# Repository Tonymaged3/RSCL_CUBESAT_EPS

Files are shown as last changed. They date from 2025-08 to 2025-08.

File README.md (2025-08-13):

# RSCL_CUBESAT_EPS
# CubeSat Electric Power System (EPS) – Senior Design Project

**Author:** Antonuos Kerollos  

## Overview
This repository contains the design files for a high-efficiency Electric Power System (EPS) intended for CubeSat missions.  
The EPS is engineered to:
- Harvest solar energy efficiently.
- Manage and protect power distribution.
- Extend battery life through intelligent switching.
- Operate reliably under harsh thermal and radiation conditions in space.

The project implements:
- Maximum Power Point Tracking (MPPT) charging.
- Custom analog automatic battery switching.
- Regulated power outputs for satellite subsystems.
- Real-time monitoring of voltage, current, and power.
- Radiation-tolerant, microcontroller-minimized control.

---

## System Architecture

**Key Subsystems:**
1. **Solar Energy Harvesting:**  
   - Monocrystalline solar panels arranged in deployable arrays for up to **5.5 W** generation under full sunlight.
   - Series pairs configuration for optimal efficiency.

2. **Battery Management:**  
   - Two battery banks (20 Ah total) with alternating charge/discharge cycles to avoid overcharging and extend lifespan.
   - Custom switching circuit using ideal diodes and comparators.

3. **Power Regulation & Distribution:**  
   - 3.3 V and 5 V regulated rails for different CubeSat loads.
   - High-side power switch for load control and protection.

4. **Monitoring & Fault Protection:**  
   - INA219 sensors for voltage, current, and power telemetry.
   - Temperature sensors for solar charger compensation.
   - Reverse current protection from solar panel transients.

5. **Deployment & Thermal Management:**  
   - Burn wire deployment for antennas and solar panels.
   - Battery heater circuit to maintain optimal operating temperature.

---
eps_block_diagram

## Component List & Circuit Roles

| Component | Type | Purpose in EPS |
|---|---|---|
| **SM401K08L** | Monocrystalline Solar Cell | High-efficiency power generation (702 mW @ 5.53 V each). |
| **LT3652** | MPPT Charger IC | Tracks solar panel maximum power point and charges battery efficiently. |
| **LTC4415** | Ideal Diode Power Path Controller | Switches between battery banks with minimal loss. |
| **TLV3012B** | Comparator | Monitors solar panel voltage to control battery switching logic. |
| **LTC3113** | DC-DC Converter | Regulates output to stable 3.3 V for CubeSat electronics. |
| **TPS61023** | Boost Converter | Regulates output to 5 V for specific subsystems. |
| **TPS1HC30** | High-Side Power Switch | Controls and protects loads from overcurrent events. |
| **INA219** | Power Monitor | Measures voltage, current, and power for real-time telemetry. |
| **TCAL9539** | I²C Expander | Extends microcontroller I/O for deployment and thermal systems. |
| **LM74610** | Ideal Diode | Prevents reverse current from solar panels. |
| **Battery Heater Circuit** | Custom | Maintains battery temperature in optimal range. |
| **Burn Wire Deployment Circuit** | Custom | Releases antennas and solar panels on command. |

---

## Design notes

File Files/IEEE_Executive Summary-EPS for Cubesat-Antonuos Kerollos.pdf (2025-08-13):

# Electric Power System Design for Reconfigurable CubeSat Clusters

Antonuos Kerollos
Department of Electrical and Computer Engineering, College of Engineering California State Polytechnic University, Pomona Pomona, CA, USA
amkerollos@cpp.edu
Faculty Advisor: Dr. Mohamed El Hadedy Aly

Abstract—This project presents the design and implementation of a high-efficiency Electric Power System (EPS) for CubeSat missions. The system addresses key challenges in space-based power management such as limited surface area for solar collection, battery longevity, space constraints, and radiation-induced failures. A custom analog-based switching topology and MPPT solar charging circuit are used to maximize power efficiency, safety, and mission reliability. Simulation and testing validate the effectiveness of the approach. A 4-layer PCB layout integrates all components for flight readiness.
Index Terms—CubeSat, Electric Power System, MPPT, LTC3652, LTC4415, Single-Event Upset, SEU, Analog Switching, PCB Design
I. INTRODUCTION

The purpose of this project is to design and implement a high-efficiency Electric Power System (EPS) that can reliably support the operation of a CubeSat throughout the duration of its mission. The EPS is the core system responsible for powering all onboard subsystems, and its performance directly impacts the mission’s success and longevity. The main objective is to deliver a compact, efficient, and reliable EPS capable of harvesting solar energy, managing power distribution, and safely storing energy in onboard batteries. The system must maintain stable voltage levels, protect components from electrical faults or any single-event upset, and provide real-time power monitoring while operating under space and weight constraints inherent to CubeSat platforms. The EPS must also prioritize energy efficiency to maximize battery life and extend the mission’s operational time.
This project addresses several key challenges:
- Maximizing energy conversion efficiency from limited solar panel surface area.
- Managing power storage and distribution for variable subsystem loads.
- Mitigating Single-Event Upsets (SEUs) caused by space radiation.
- Operating within strict space and mass constraints.
- Ensuring system stability and safety in high-temperature environments.
- Providing real-time monitoring and control to adapt to orbital power conditions.

II. LITERATURE REVIEW

The first and most critical problem addressed in our design is the efficiency gap between the amount of solar energy that can be harvested and how much of that energy can be effectively stored in the batteries. To address this, we selected the SM401K08L monocrystalline solar cell, rated at 702 mW and 5.53 V, with physical dimensions of 90 mm × 40 mm. Two cells are connected in series to produce up to 1.4 W per pair. This configuration is significantly more space-efficient than other CubeSat approaches that rely on either a single large panel or many smaller panels, which often suffer from power losses due to wiring resistance and interconnect complexity. By integrating five series-connected pairs—mounted on the top and four sides of the CubeSat—and deploying them using a mechanism similar to antenna deployment systems, we can generate up to 5.5 W under full sun exposure.
To convert and store the harvested energy, we employed the LT3652 Maximum Power Point Tracking (MPPT) charger. This IC dynamically adjusts its input to extract the maximum available power from the solar panels. Unlike traditional EPS designs that connect the charger output in parallel with both the load and the batteries, our design isolates these paths to avoid overcharging risks. In parallel configurations, the battery may continue charging unnecessarily when the load is drawing current, even after the battery is full. Additionally, this setup causes the battery to operate in a narrow voltage range and frequently alternate between charging and discharging states, which accelerates degradation.
To overcome these issues, we designed a custom analog automatic power switch circuit. This circuit separates the energy storage into two independent battery units. One unit is isolated for charging, while the other supplies power to the load. The LT3652 is connected in series with the charging battery, allowing it to monitor charge conditions accurately. The switching mechanism uses an LTC4415 ideal diode and is controlled by a TLV3012B comparator, which senses solar panel voltage. When sunlight is available, the comparator toggles the switch to isolate the charging battery and route the load to the other unit. Once solar input is lost, the switch reverts, making the charged battery available to the system and isolating the other for recharging in the next cycle.

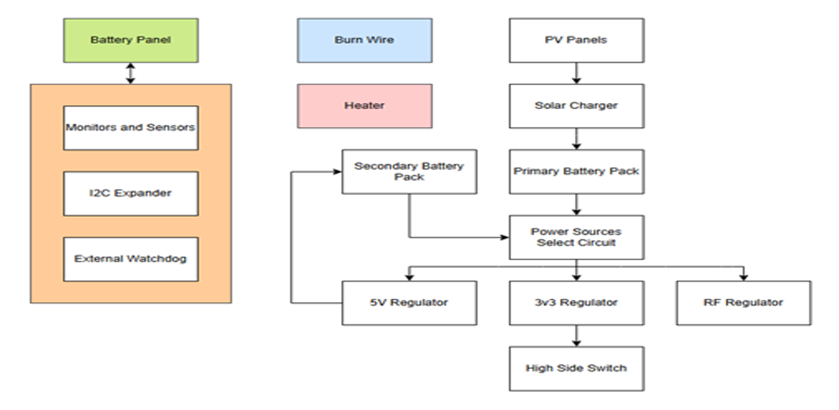
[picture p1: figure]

Fig. 1: Electrical Power System Block Diagram showing solar input, switching logic, MPPT charging, regulation, and battery units.

For efficient energy distribution, we used low-power regulators: the LTC3113 for 3.3V and the TPS61023 for 5V output. These deliver stable voltage rails for the CubeSat subsystems. A TPS1HC30 high-side switch protects the power path, and INA219 sensors are integrated to monitor current, voltage, and power in real time, providing telemetry to the main microcontroller.
To increase radiation resilience, the EPS logic minimizes reliance on digital microcontrollers and register-based logic. Instead, analog circuitry is used for core operations, significantly reducing susceptibility to Single-Event Upsets (SEUs)—bitflipping events caused by high-energy particles in space. This analog-dominant architecture avoids runtime-dependent firmware and volatile memory, enhancing system robustness in radiation-prone orbits.
All components are selected to operate reliably up to 125°C, ensuring thermal resilience in lunar orbit conditions. Three temperature sensors are also added to the solar charger to compensate for panel voltage shifts due to thermal variations. The open-circuit voltage temperature coefficient of –13.92 mV/K is dynamically corrected, improving energy capture under fluctuating conditions—a feature rarely seen in comparable CubeSat systems.
For expanded control, we integrated a TCAL9539 I²C expander, allowing the MCU to programmatically pull pins high or low. This enables manual overrides and control of subsystems, such as the thermal and deployment circuits. Additionally, LM74610 ideal diodes were added to prevent reverse current flow from the solar panels into the charging path.
Finally, the EPS board includes a burn-wire circuit for both antenna and solar panel deployment, as well as a battery heater circuit to maintain the batteries within optimal operating temperatures. Both circuits are controlled by the MCU through the I²C expander, ensuring reliable execution of missioncritical functions across varying orbital environments.

III. RESULTS AND DISCUSSION

To validate the performance and reliability of the power management system, we conducted multiple simulations and hardware tests focusing on the automatic switching topology, solar energy harvesting, battery behavior, and charging efficiency.
Using LTspice, I simulated the auto-switching power management circuitry. This design uses a TLV3012B comparator to control the enable pin of the LTC4415 power path controller, toggling between two battery units based on solar panel voltage levels. In the simulation, a pulse generator was used to mimic the behavior of the comparator, switching the control logic depending on light availability.

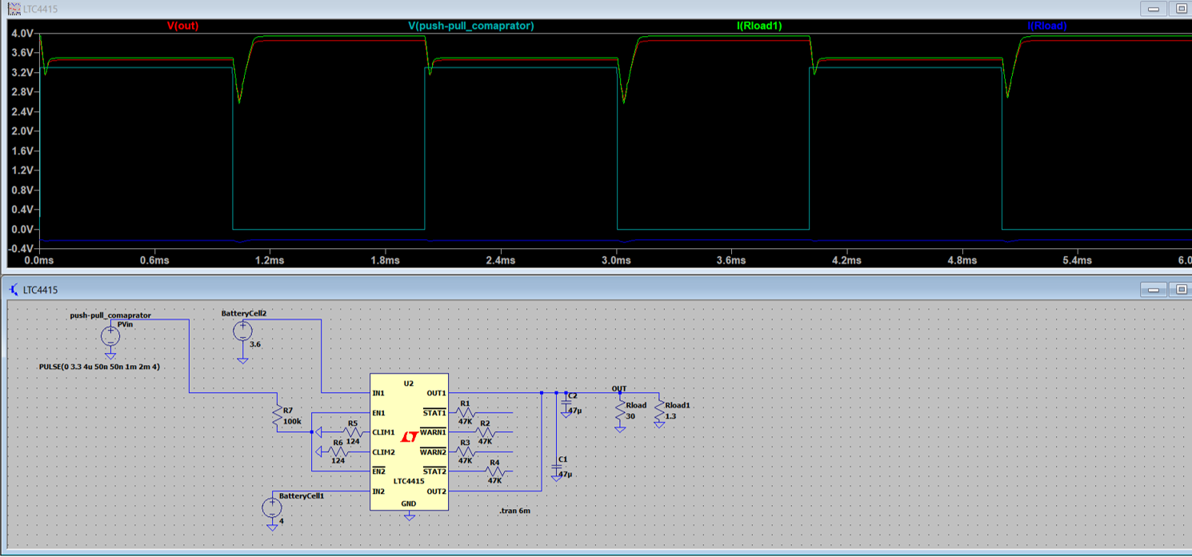
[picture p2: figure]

Fig. 2: LTSpice Simulation for the Auto-Switching Circuit

We tested different output capacitances to evaluate the voltage and current drop during switching events. When using an 80 µF capacitor at the output of the LTC4415, the simulation showed a 360 mV (11%) voltage drop and a 100 mA (10%) current drop. These transient variations are within acceptable limits and do not adversely affect the load. Further optimization using two 47 µF capacitors reduced these drops to 7%, confirming that the switching topology operates efficiently and can handle transitions without significantly impacting system stability.
In addition to simulations, real hardware components were evaluated. The solar panels were tested under standard illumination, and their current and voltage outputs matched rated specifications, validating our theoretical calculations. Similarly, the Li-ion batteries were tested to ensure their voltage, capacity, and charging behavior were within expected tolerances.
We also tested the LT3652 MPPT charger, which successfully activated its fault detection outputs. However, it failed to begin charging during early tests due to the exposed thermal pad not being properly connected to ground, a known requirement per the datasheet. Once addressed in the PCB layout, proper charging behavior is expected.
The use of flight-proven components throughout the EPS design, including the LTC4415, LT3652, TPS61023, and INA219, provided additional confidence in system reliability. Many of these ICs have heritage in previous CubeSat missions, further reinforcing their suitability for space applications.
We also conducted a power rating and efficacy study for our EPS. The energy conversion efficacy due to typical losses (resistance, wiring, and hardware) was estimated between 70% and 90%. Using this factor:
- A pair of panels in series: 1404 mW × 0.8 = 1.1 W

- Three series pairs: 3 × 1.1 W = 3.3 W
- Four series pairs: 4 × 1.1 W = 4.4 W
With five pairs of solar panels, the estimated total power generated is approximately 5.5 W under full sun exposure. For storage, the system uses four 5000 mAh batteries, totaling 20 Ah. Based on a conservative energy availability estimate in Low Lunar Orbit (LLO)—where sunlight is guaranteed for at least 30 minutes per 2-hour orbital period—we expect to generate a minimum of 2 W per cycle. Assuming the load requires 1 W per hour, the power budget is sufficient to support basic CubeSat operations with redundancy, while also compensating for periods of eclipse or reduced solar exposure. These results confirm that the EPS topology functions as intended, with reliable energy harvesting, intelligent switching, and regulated power delivery, while maintaining operational safety and extending battery and mission life.
In addition to simulation and component-level testing, a complete schematic of the entire Electric Power System was implemented, followed by full 4-layer PCB layout and routing. The board was designed to integrate all power generation, regulation, switching, and monitoring components into a compact, reliable form factor suitable for CubeSat deployment. Signal, ground, and power planes were carefully distributed across the four layers to optimize thermal performance, reduce EMI, and ensure power integrity. Input/output pins and onboard connectors were also included to support integration with the satellite’s batteries, solar panels, and other subsystems. The layout emphasizes low-resistance paths for high-current traces, controlled impedance for signal lines, and overall electrical and thermal robustness. While the design is ready for fabrication and testing, a final round of routing refinement and design rule verification is required to ensure compliance with fabrication constraints and improve long-term reliability.

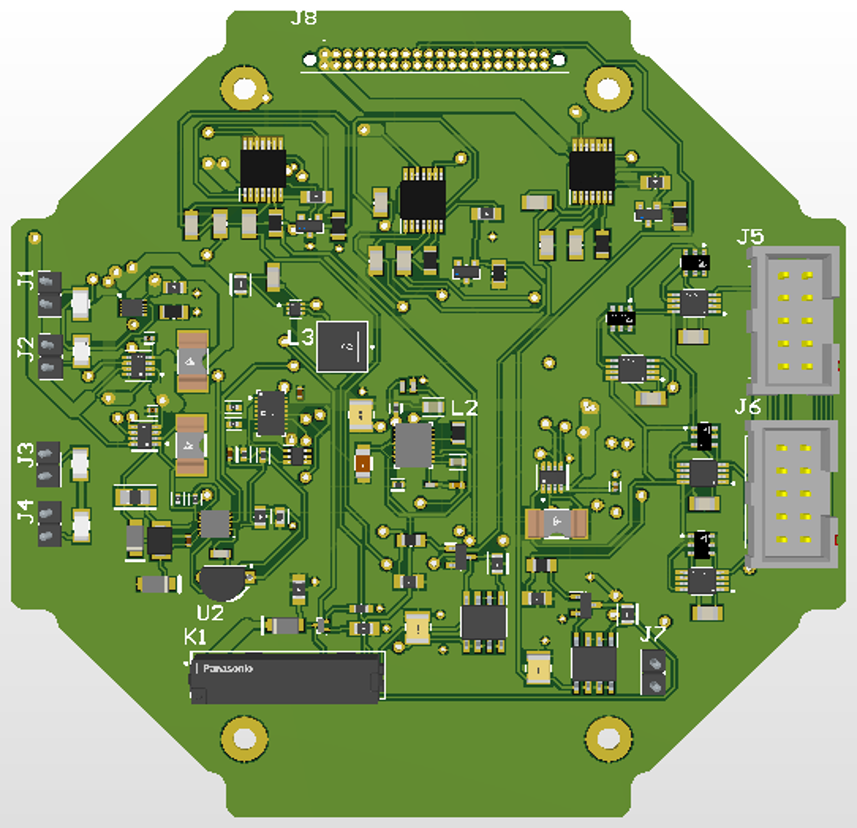
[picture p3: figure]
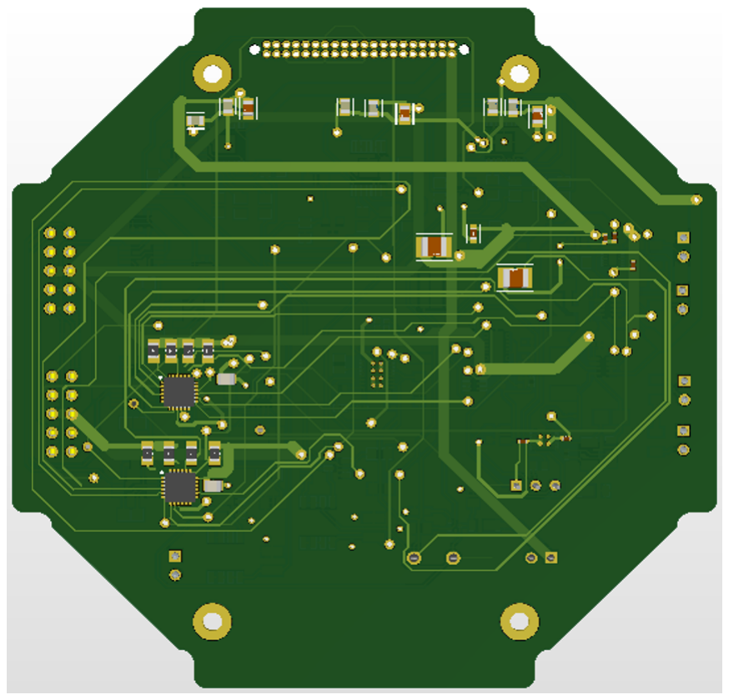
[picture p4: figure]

(a) Top layer view | (b) Bottom layer view

Fig. 3: CubeSat EPS PCB Design showing both top and bottom layout layers.

IV. CONCLUSION
This project successfully delivers a comprehensive and efficient Electric Power System (EPS) tailored to the constraints and requirements of CubeSat missions. By systematically addressing the core challenges in space-based power design, the final implementation demonstrates both innovation and reliability. The use of high-efficiency monocrystalline solar panels, coupled with an advanced MPPT charging system, ensures maximum energy extraction from the limited available surface area. The custom analog-based power switching topology enables intelligent battery management, avoiding harmful charge-discharge cycles and significantly extending battery life.
Space and mass constraints were overcome through a compact 4-layer PCB layout that integrates all subsystems including regulation, monitoring, fault protection, and thermal management into a single board. The design supports stable operation in extreme temperature environments, with all components rated up to 125°C and thermal feedback mechanisms included for improved energy conversion under changing conditions. Real-time power monitoring is enabled via lowoverhead digital sensors and an I²C expander, while critical safety functions like deployment and heating are directly controlled through onboard logic.
Importantly, the system minimizes dependence on microcontrollers and register-based digital logic, reducing vulnerability to radiation-induced Single-Event Upsets (SEUs) and enhancing overall mission resilience. With the full schematic implemented and a 4-layer PCB routed and ready for fabrication, the EPS is positioned as a robust, flight-ready solution. Once final routing refinements are completed, the board will be ready for manufacturing and integration. The design not only meets mission objectives for reliability and efficiency but also offers modular and scalable power architecture applicable to future CubeSat and small satellite platforms.

ACKNOWLEDGMENT
The author would like to sincerely thank Dr. Mohamed El Hadedy Aly for his continued guidance and support as the faculty advisor for this project. His expertise and feedback were instrumental throughout the design and development of the CubeSat Electric Power System. For correspondence, he may be reached at mealy@cpp.edu.

REFERENCES

[1] PyCubed, PyCubed Hardware GitHub Repository. [Online]. Available: https://github.com/pycubed/hardware/tree/master
[2] NASA, CubeSat 101: Basic Concepts and Processes for First-Time CubeSat Developers. NASA, Mar. 2017. [Online]. Available: https://www.nasa.gov/wp-content/uploads/2017/03/nasa csli cubesat 101 508.pdf
[3] United Nations Office for Outer Space Affairs (UNOOSA), KiboCUBE Academy 2021 – On-demand Pre-recorded Lecture: EPS Design Considerations. [Online]. Available: https://www.unoosa.org/documents/pdf/psa/access2space4all/KiboCUBE/AcademySeason2/On-demand Pre-recorded Lectures/KiboCUBE Academy 2021 OPL08.pdf
[4] M. Holliday, K. Tracy, Z. Manchester, and A. Nguyen, “The V-R3x Mission: Towards Autonomous Networking and Navigation for CubeSat Swarms,” 4S Symposium, 2022. [Online]. Available: https://rexlab.ri.cmu.edu/papers/vr3x.pdf

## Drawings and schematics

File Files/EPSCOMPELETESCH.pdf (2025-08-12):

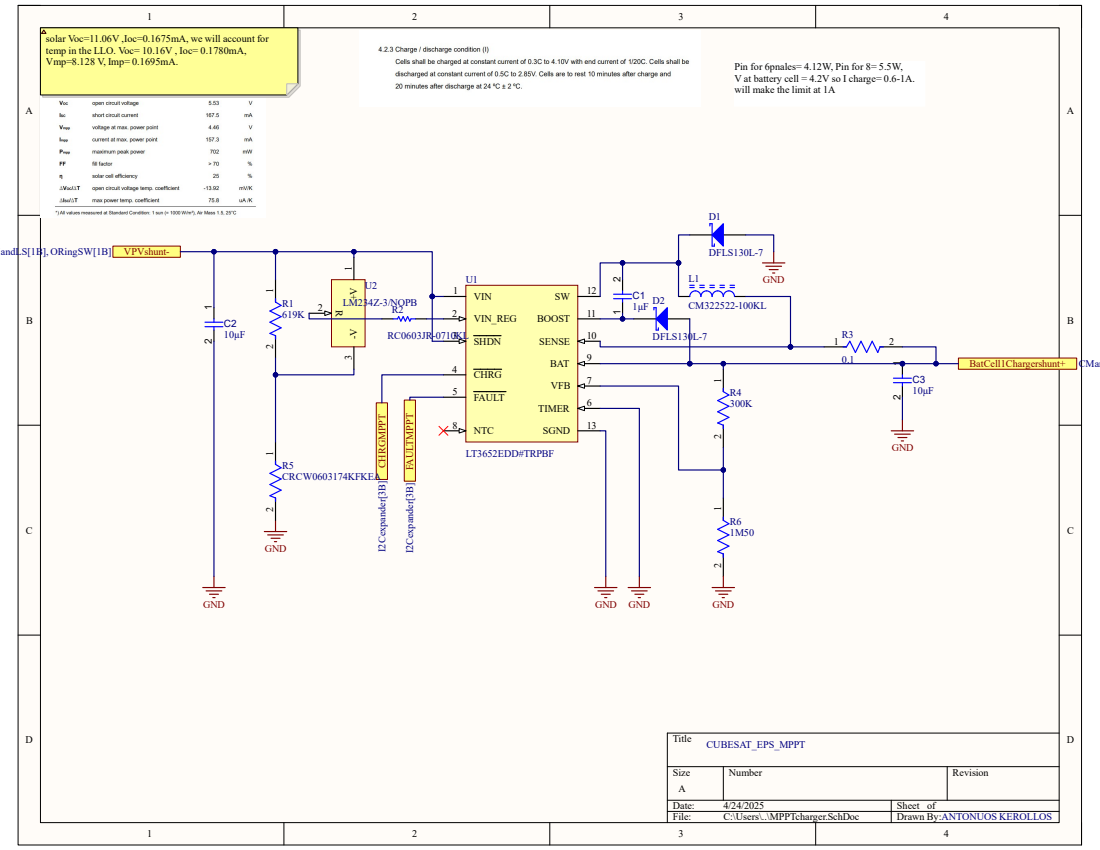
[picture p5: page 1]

solar Voc=11.06V ,Ioc=0.1675mA, we will account for
temp in the LLO. Voc= 10.16V , Ioc= 0.1780mA,
Vmp=8.128 V, Imp= 0.1695mA.

Pin for 6pnales= 4.12W, Pin for 8= 5.5W,
V at battery cell = 4.2V so I charge= 0.6-1A.
will make the limit at 1A

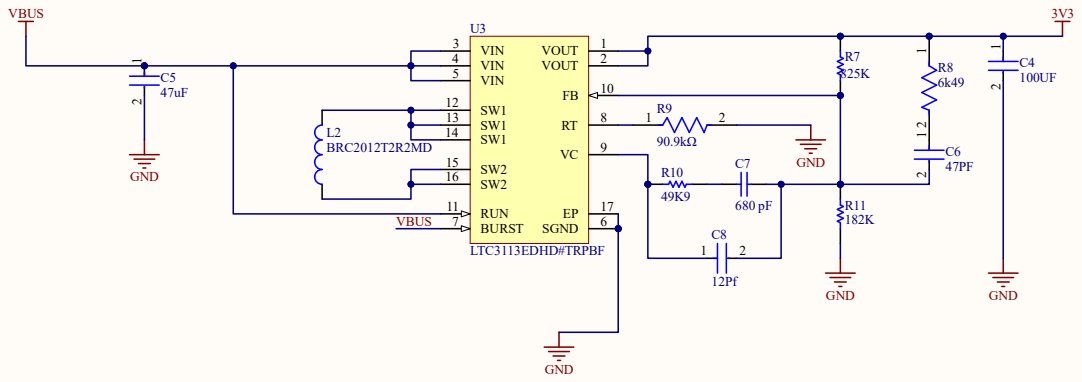
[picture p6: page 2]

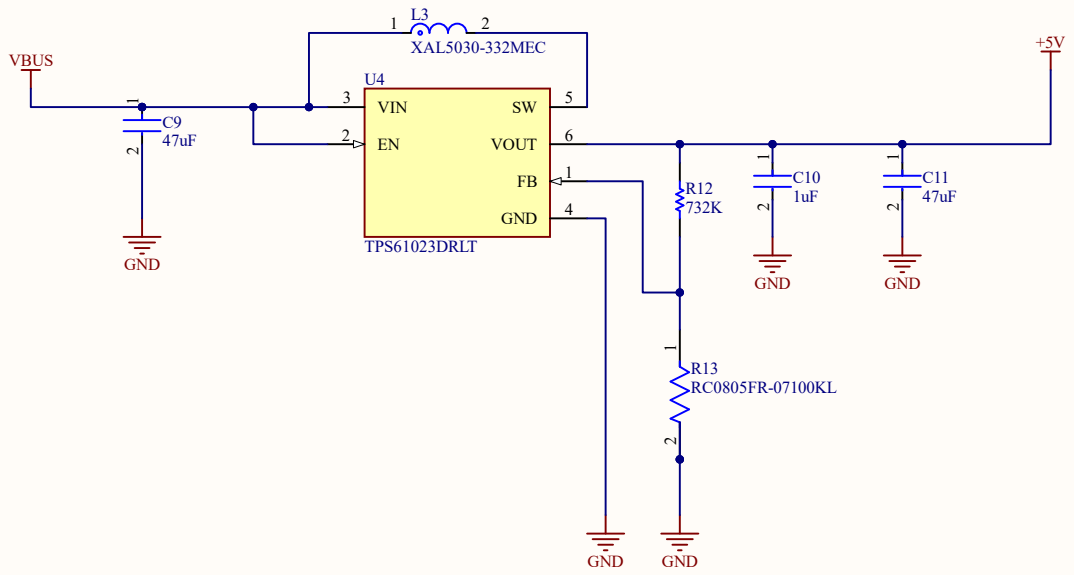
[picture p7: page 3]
Title; Size; Number; Revision; File:; C:\Users\..\REG5V.SchDoc; Drawn By:; VIN 3; VOUT; GND; TPS61023DRLT; VBUS; XAL5030-332MEC; CUBESAT_EPS_REG5V

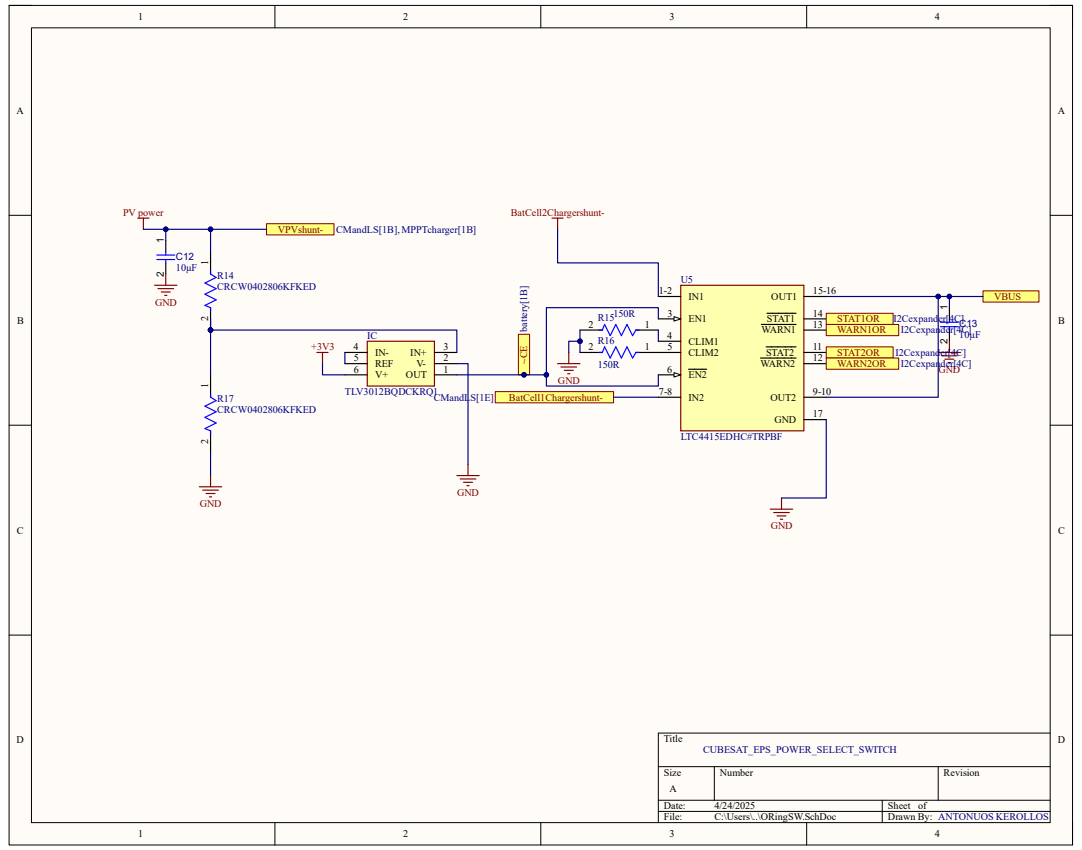
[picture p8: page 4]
Title; Size; Number; Revision; File:; C:\Users\..\ORingSW.SchDoc; Drawn By:; CLIM1 4 CLIM2 5; OUT1; OUT2; STAT1; STAT2; WARN1; WARN2; GND; LTC4415EDHC#TRPBF; PV power; VBUS; GND ~CE battery[1B]; STAT1OR I2Cexpander[4C]; WARN1OR; I2Cexpander[4C]; STAT2OR; WARN2OR; BatCell2Chargershunt-; CMandLS[1E]; BatCell1Chargershunt-; OUT; REF 5; TLV3012BQDCKRQ1; R14 CRCW0402806KFKED 1 2; R17 CRCW0402806KFKED; CUBESAT_EPS_POWER_SELECT_SWITCH

VPVshunt- CMandLS[1B], MPPTcharger[1B]

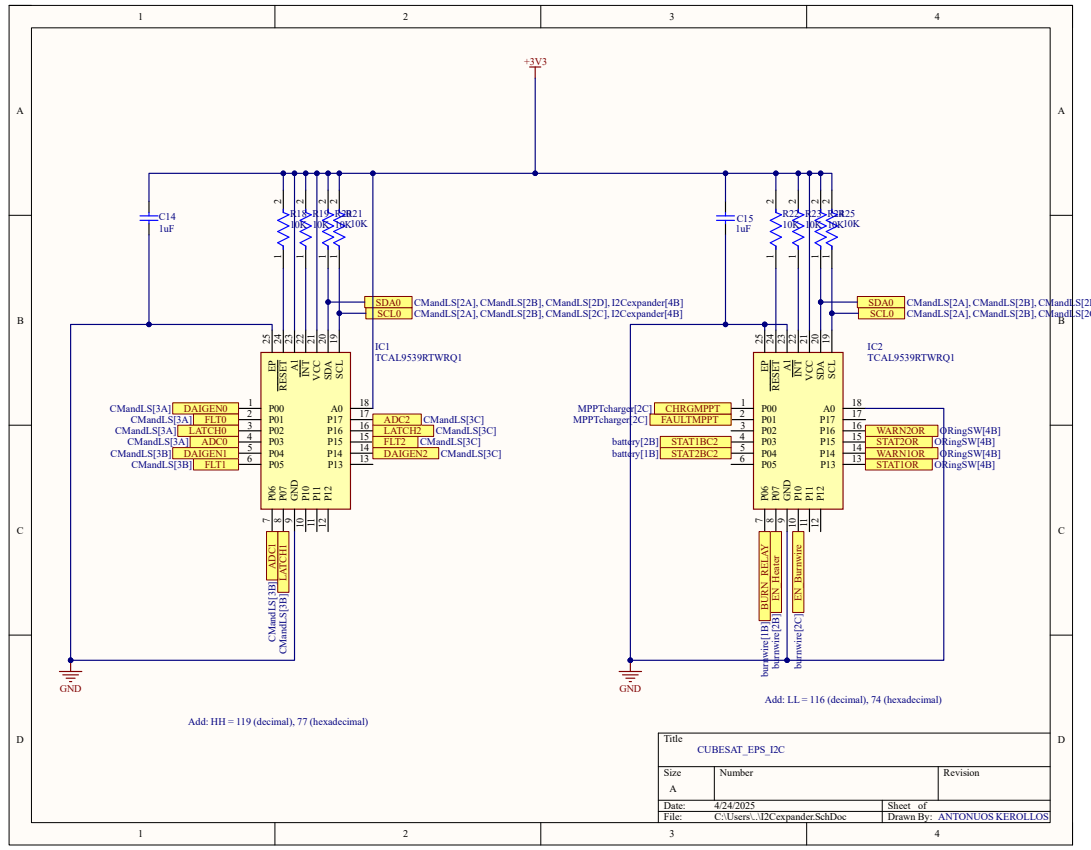
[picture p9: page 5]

Add: LL = 116 (decimal), 74 (hexadecimal)

Add: HH = 119 (decimal), 77 (hexadecimal)

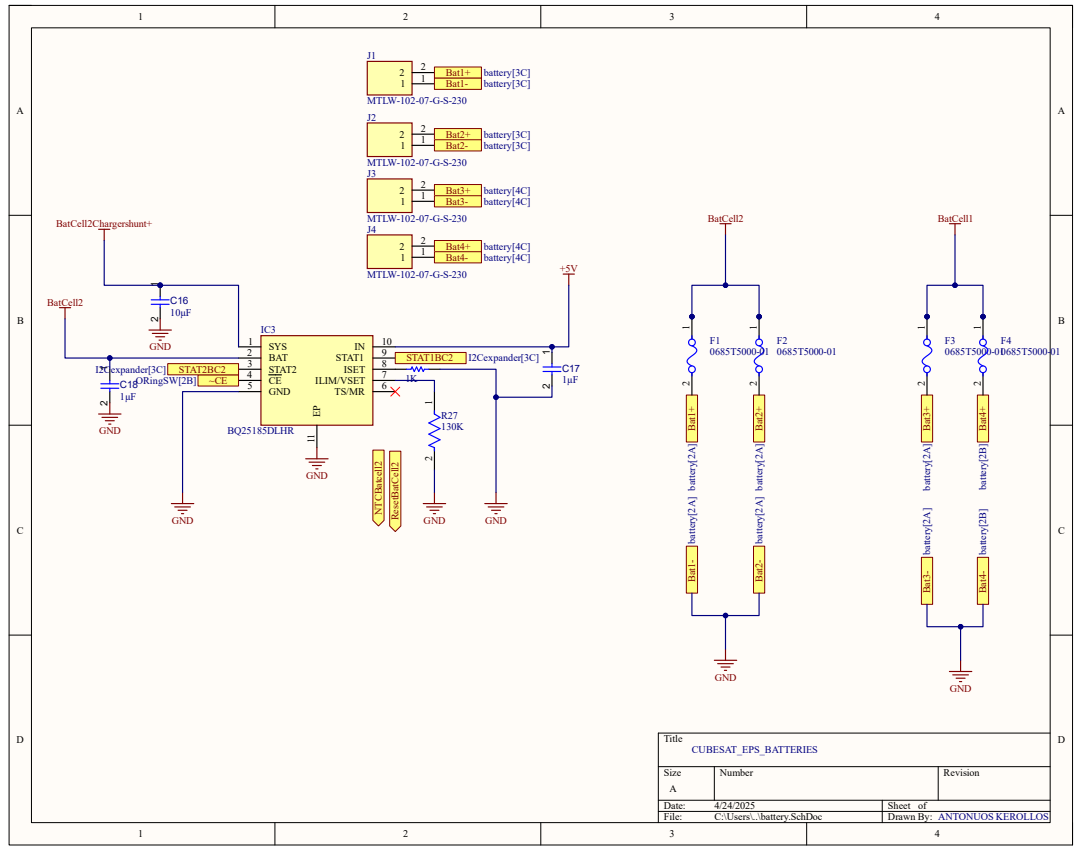
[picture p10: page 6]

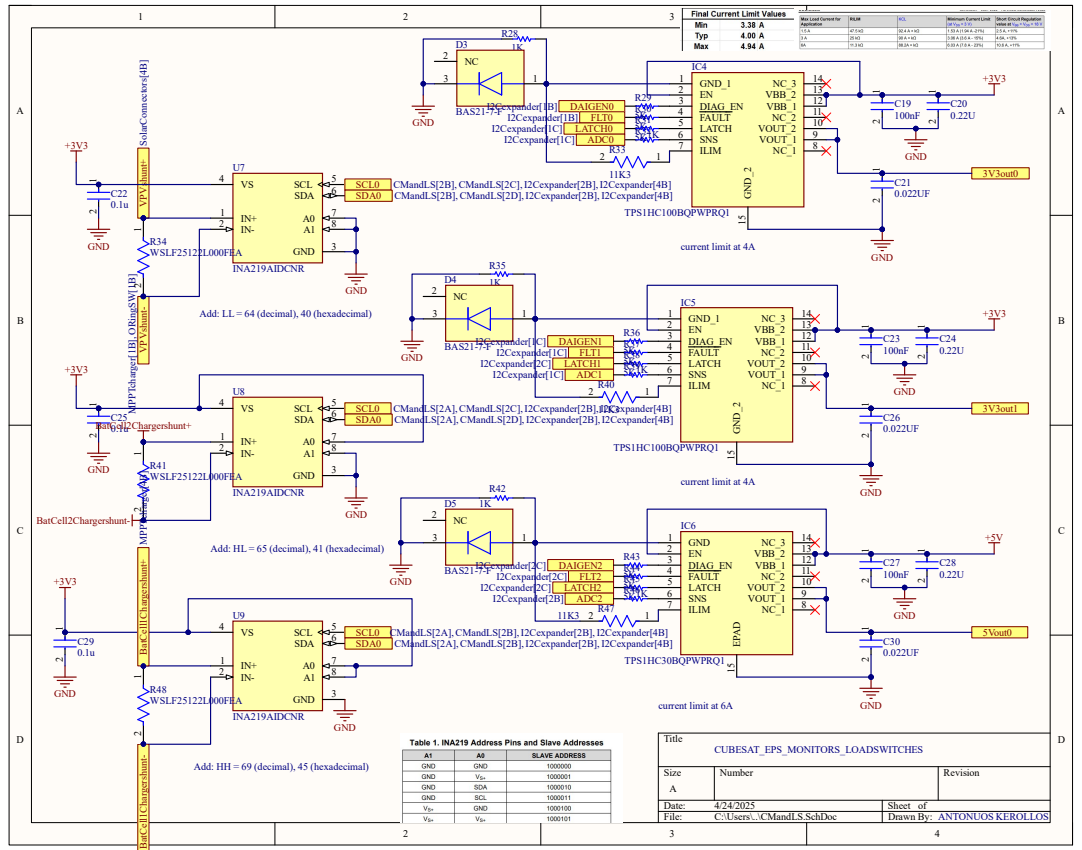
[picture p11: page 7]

5K VPVshunt- MPPTcharger[1B], ORingSW[1B] VPVshunt+ SolarConnectors[4B] 1 2

Add: LL = 64 (decimal), 40 (hexadecimal)

Add: HL = 65 (decimal), 41 (hexadecimal)

Add: HH = 69 (decimal), 45 (hexadecimal)

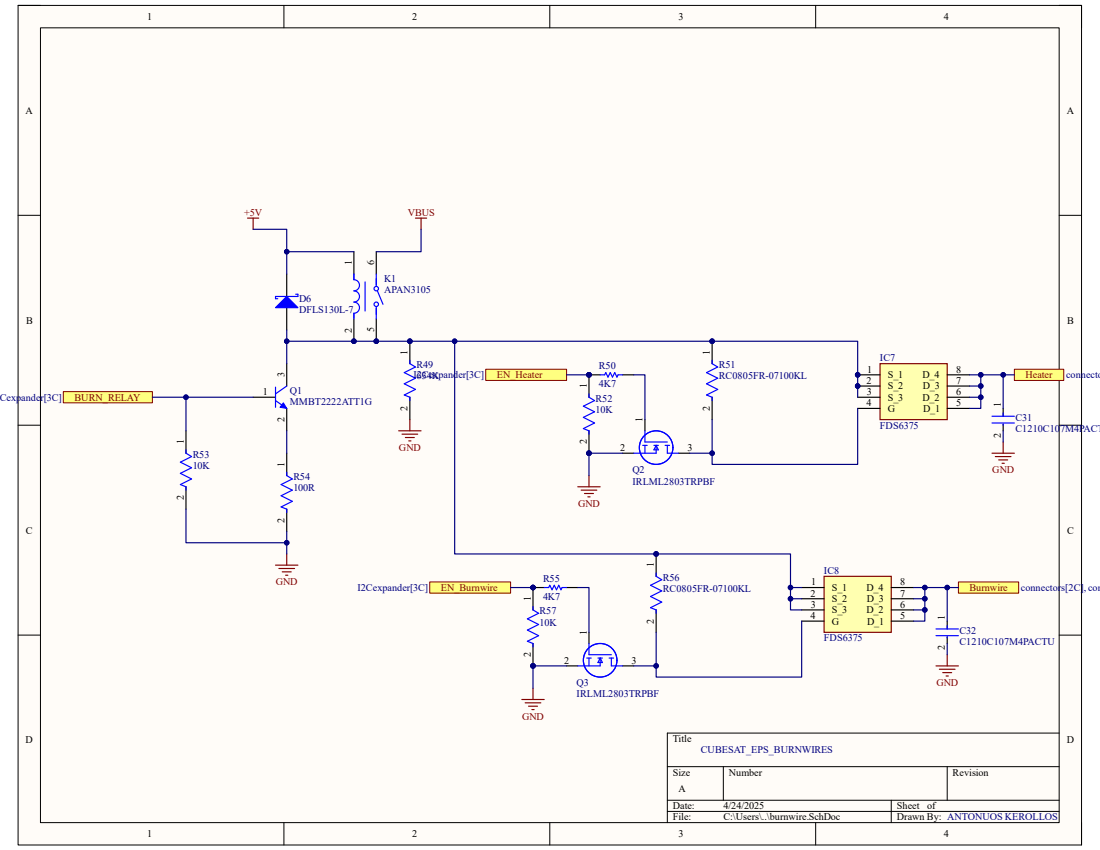
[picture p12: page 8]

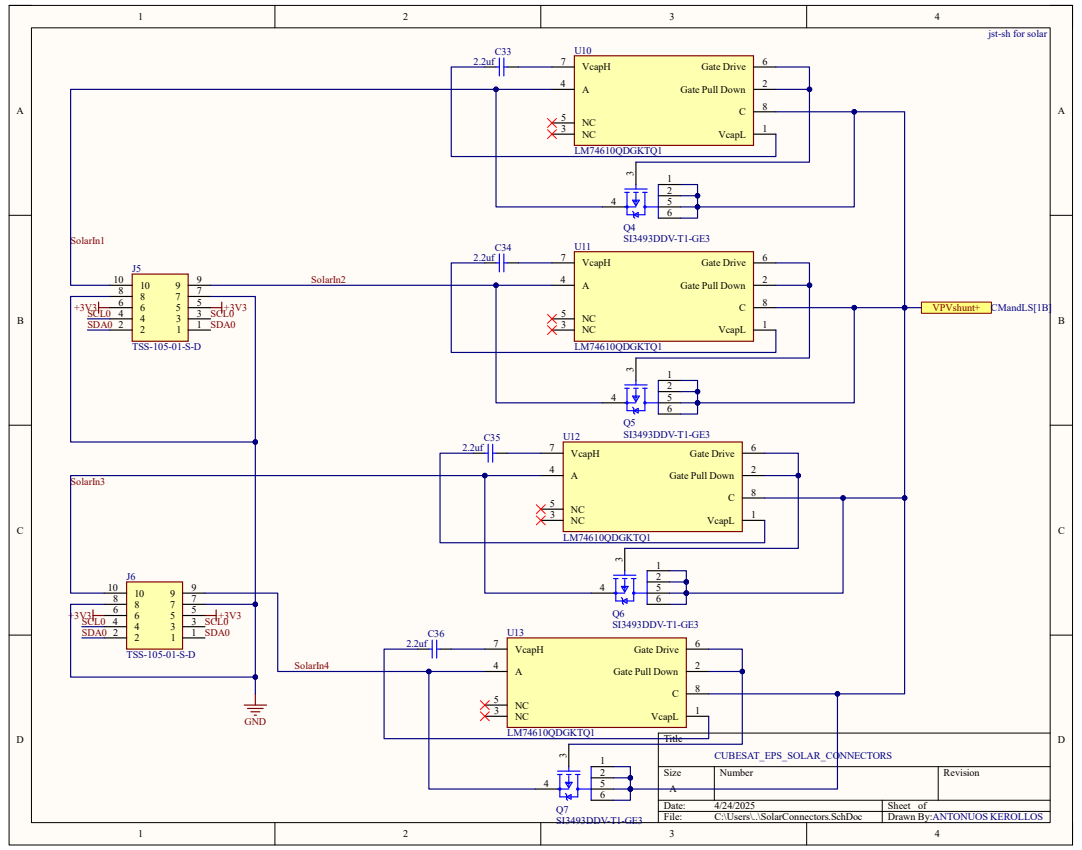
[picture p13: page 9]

jst-sh for solar

D D

C C

B B

A A

Title

Size | Number | Revision
File: | C:\Users\..\connectors.SchDoc | Drawn By:

1

1
2

2

J7

MTLW-102-07-G-S-230

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
10 | 10 11 11 | 12 | 12 13 13 | 14 | 14 15 15 | 16 | 16 17 17 | 18 | 18 19 19 | 20 | 20 21 21 | 22 | 22 23 23 | 24 | 24 25 25 | 26 | 26 27 27 | 28 | 28 29 29 | 30 | 30 31 31 | 32 | 32 33 33 | 34 | 34 35 35 | 36 | 36 37 37 | 38 | 38 39 39 | 40 | 40

J8

SFM-120-L3-L-D-A

connectors[2C], connectors[3B], connectors[3C] +5V | +5V | connectors[2C], connectors[3B], connectors[3C]
connectors[2C], connectors[3B], connectors[3C] +5V | +5V | connectors[2C], connectors[3B], connectors[3C]
connectors[2B], connectors[2C], connectors[3C] GND | GND | connectors[2B], connectors[2C], connectors[3C]
connectors[2B], connectors[2C], connectors[3C] GND | GND | connectors[2B], connectors[2C], connectors[3C]
connectors[2B], connectors[2C], connectors[3C] GND | GND | connectors[2B], connectors[2C], connectors[3C]
connectors[2B], connectors[2C], connectors[3C] GND | GND | connectors[2B], connectors[2C], connectors[3C]
connectors[2C], connectors[3A], connectors[3B], connectors[3C] +3V3 | +3V3 connectors[2B], connectors[2C], connectors[3A], connectors[3C]
connectors[2B], connectors[2C], connectors[3A], connectors[3B], connectors[3C] +3V3 | +3V3 connectors[2B], connectors[2C], connectors[3A], connectors[3B], connectors[3C]
connectors[2B], connectors[2C], connectors[3A], connectors[3B], connectors[3C] +3V3 | +3V3 connectors[2B], connectors[2C], connectors[3A], connectors[3B], connectors[3C]
connectors[2B], connectors[2C], connectors[3C] GND | GND | connectors[2B], connectors[2C], connectors[3C]
| SCL | connectors[3C]
SCL | connectors[3C]
SCL | connectors[3C]

connectors[2C] SDA

connectors[2C] SDA

connectors[2C] SDA

connectors[2C], connectors[3C] GND

GND

+3V3
+3V3 connectors[2B], connectors[2C], connectors[3B], connectors[3C]

connectors[2C], connectors[3C] +5V

+5V

burnwire[4B], connectors[3C] Heater | Heater burnwire[4B], connectors[2C]
burnwire[4C], connectors[3C] Burnwire | Burnwire burnwire[4C], connectors[2C]
connectors[2B], connectors[2C], connectors[3C] GND

connectors[2B], connectors[2C], connectors[3C] GND

GND | connectors[2B], connectors[2C], connectors[3C]
GND | connectors[2B], connectors[2C], connectors[3C]

CUBESAT_EPS_CONNECTORS
